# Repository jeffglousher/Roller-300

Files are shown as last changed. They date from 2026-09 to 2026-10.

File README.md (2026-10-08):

# Roller-300

Two-wheel indoor roller under mechanical development. Start the S21 rigid belt drivetrain with the **five-part receiving-fit test**, PETG /0.4mm on the X2D. The larger carrier/fixture and open-face wheel follow successful hardware fits. Whole-chassis fit remains incomplete: the historical hatch collides when restored and electronics mounts are inactive. Strength optimization and powered loads are deferred.

- [Roller-300.nbcad](Roller-300.nbcad): current native CAD model,2,033 features and seven assembly Named Views.
- [Whole-chassis fit review](design/chassis-fit-review-2026-10-07/README.md): native service/access fixes, open-face wheels, exact fit checks and remaining chassis gaps.
- [Adversarial review](design/adversarial-review-2026-10-06/README.md): corrected defects, native images and validation scope.
- [PLAN.md](PLAN.md): current dimensions, retention and assembly order.
- [Small Bambu fit project](first-prints/receiving-fit-gate-2026-10-06/Roller-300-small-fit-gate.3mf): five interfaces, approximately25.48g /1h16m. Open this first.
- [S21 open-face wheel fit project](first-prints/chassis-fit-2026-10-07/outboard-down/Roller-300-wheel-open-fit.3mf): approximately336.71g /8h38m; print after receiving fits pass. Supersedes the closed-wheel files.
- [Fresh print decision](design/print-decision-2026-10-06/README.md): fresh native replay, actual toolpaths and corrected support/settings defects. The original ten-part review plate is superseded.
- [Print set](first-prints/adversarial-fit-2026-10-06/README.md): all eleven pieces and individual slicer checks.
- [BOM.xlsx](BOM.xlsx) and [parts-sources.json](parts-sources.json): current purchase workbook and source record.
- [parameters.json](parameters.json) and [test-record.json](test-record.json): current nominal values, evidence and pending physical tests.

Geometry is authored/replayed and rendered by the installed native CAD application. STEP-based inspection probes and rigid print placement support validation. No print, powered test or purchase has been made. Historical chapter files and previous print folders are retained for reference.

The public repository is https://github.com/jeffglousher/Roller-300. No hardware/source license has been assigned; linked third-party material retains its own terms.

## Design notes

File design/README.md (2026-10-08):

# design/

## Current S20 drivetrain

[Adversarial review](adversarial-review-2026-10-06/README.md) contains the current native captures, exact interference and geometry checks. [Canonical CAD](../Roller-300.nbcad) and [PLAN.md](../PLAN.md) define the current assembly. The chapter files below are historical baselines and do not regenerate S20.

VERSION 0.1 chapters (`VERSION`, `gen_meta.json`). Filenames are `design_v0_1_<role>.nbcad.jsonc`. The `"version": 1` field inside each file is the script schema.

Mechanical decisions are in [`../PLAN.md`](../PLAN.md). Dimensions are in [`../parameters.json`](../parameters.json). The native desktop model is [`../Roller-300.nbcad`](../Roller-300.nbcad).

## Chapters

| File | Stage | Role | Contents |
|---|---|---|---|
| `design_v0_1_hardware_refs.nbcad.jsonc` | S01 | Bearing and nut coupons | Trial 608 seat D22.2×7.2 and M4 nut pocket AF 7.3×3.5 |
| `design_v0_1_barrel_shell.nbcad.jsonc` | S02 | `main_shell` (body 32) | Shell chapter. Standalone file skips MoveCopy5, Combine8, and Combine16. Assemble-order AABB about 159.93×210×159.96. Meshes: `../first-prints/native-port/main-shell.*` |
| `design_v0_1_input_carriage.nbcad.jsonc` | S02 | `left_input_carriage` (body 97) | Left carriage. AABB 39×100×35. Meshes: `../first-prints/native-port/left-input-carriage.*` |
| `design_v0_1_input_caps.nbcad.jsonc` | S02 | Input caps (bodies 100, 108) | Inner and outer. AABB 39×8×17.7. Meshes: `../first-prints/native-port/input-cap-{inner,outer}.*` |
| `design_v0_1_wheel_caps.nbcad.jsonc` | S02 | Wheel caps (bodies 56, 65) | Inner and outer. AABB 50×12×16.7. Meshes: `../first-prints/native-port/wheel-cap-{inner,outer}.*` |
| `design_v0_1_structural_hatch.nbcad.jsonc` | S03 | `hatch` (body 141) | Replay after the shell chapter through Combine3. AABB 138×179.4×79.932. The review STL in `shell-first-review/` is the trimmed export (zmin 154.859). Meshes: `../first-prints/native-port/curved-hatch.*` |
| `design_v0_1_electronics_mounts.nbcad.jsonc` | S04 | Shelf and allowance coupons | Pi, Pixracer, TOF, battery tray, and thermal shelf from recorded nominals. Positive retainers, sensor depth, and the optical aperture stay open until the parts are measured |
| `design_v0_1_drive_stack.nbcad.jsonc` | S01/S05 | Drive envelopes | 24/48 pitch circles, belt torus, and Ø8 stubs. These are envelopes, not tooth geometry |
| `design_v0_1_assemble.nbcad.jsonc` | orchestrator | Chapter order | Empty steps. Order is listed in that file and in `gen_meta.json` → `assemble.chapter_order` |

## Replay

Open a blank document and apply the chapters in `assemble.chapter_order`. These files have no include. A runner has to apply each chapter's steps and remap `$ref` / `let` bindings.

Frame: millimeters; X forward, Y left, Z up; axle Z=123.

Belt cited on the drive chapter: D&D 210-3M-09, pitch 3 mm, pitch length 210 mm, width 9 mm, 70 teeth.

## Meshes

- [`../first-prints/coupons/`](../first-prints/coupons/README.md) — fit coupons
- [`../first-prints/shell-first-review/`](../first-prints/shell-first-review/README.md) — review meshes from the native model
- [`../first-prints/native-port/`](../first-prints/native-port/README.md) — meshes replayed from these chapters

Feature dumps of the native bodies are in [`native-port/`](native-port/README.md).

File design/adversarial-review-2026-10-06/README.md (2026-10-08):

# S20 adversarial drivetrain review

Printing recommendation updated by the [fresh print decision](../print-decision-2026-10-06/README.md): start with the corrected five-part receiving-fit plate. The original ten-part review project is superseded by actual support/bed/settings findings. The geometry and nominal inspection evidence below remain applicable.

S20 corrects assembly defects in the prior nominal model and prepares an unpowered PETG one-drive fit article. [Current model](../../Roller-300.nbcad) and [assembly instructions](../../PLAN.md) are authoritative. No physical validation or powered release is claimed.

## Defects corrected

The earlier shared servo and bridge datums had moved repeatedly. The reference servo ears were12mm from their intended position, bridge bores missed the bridge, and restraints intersected the servo. Native overlap volumes included72.9mm³ with the roof-open fixture,307.8mm³ with its carrier and353.27mm³ with its bridge. Datums/reference ears are now coherent and stationary clearances pass at tested carrier travel.

The bridge lacked valid captures at its actual mounting points. S20 adds rounded posts, side-loaded bridge nuts, four captured ear nuts and lower driver passages. Nut seating, insertion and resistance to rotation are tested against the native solids. Loose nuts require a screw for captivity; a snap fit is not claimed.

The adapter's rotating pinch ear touched its carrier. The24T pulley's5mm clamp hub also could not enclose a conventional M3 nut. Both friction clamps are removed. A stock48mm REX shaft drives AF7.3 printed bores, with factory Eclip and stock rear retention. This simplifies assembly and avoids a fabricated thin collar and1.7mm shim stack.

A positive keyed bore needed a separate axial stop. Integral R5.5 pulley lands now locate it between bearing inner races, leaving0.4mm nominal total play. The shaft uses the Eclip pocket and rear metal stack for0.2mm nominal travel. Native probes verify permitted movement and interference beyond the stops. This establishes nominal geometry, not wear/load capacity.

The output8mm stop now uses stock6+2mm spacers. Right purchased threaded references use rotation, preserving right-hand thread geometry. Printed parts retain their intended mirror geometry.

## Native CAD images

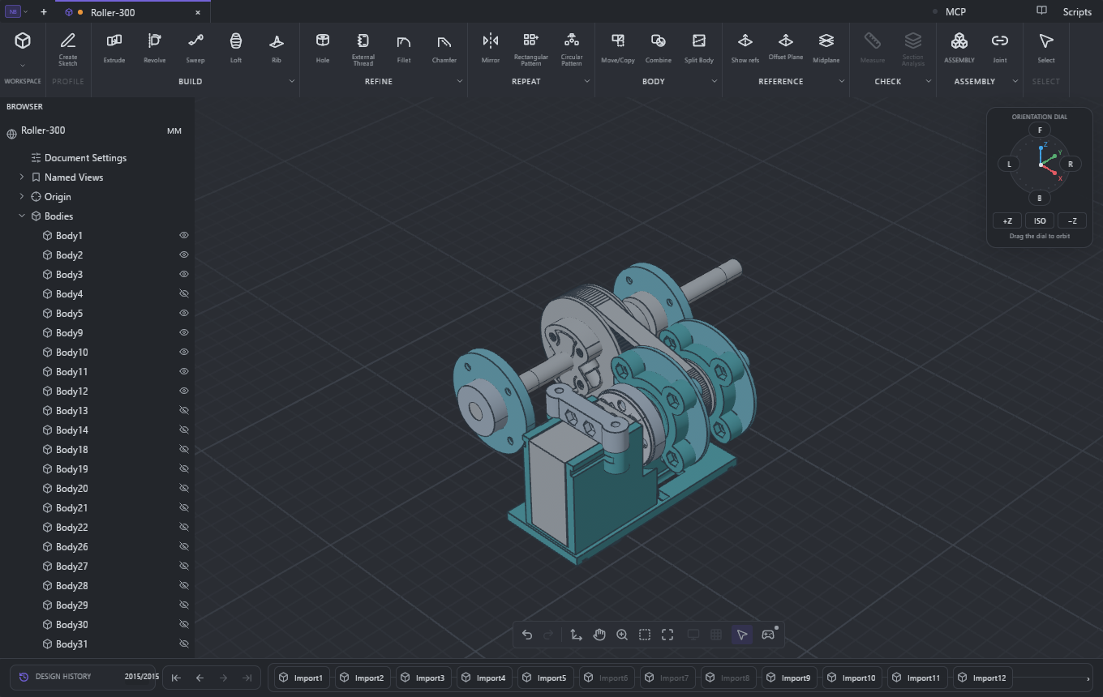
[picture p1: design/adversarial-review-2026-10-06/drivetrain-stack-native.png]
One-drive stack


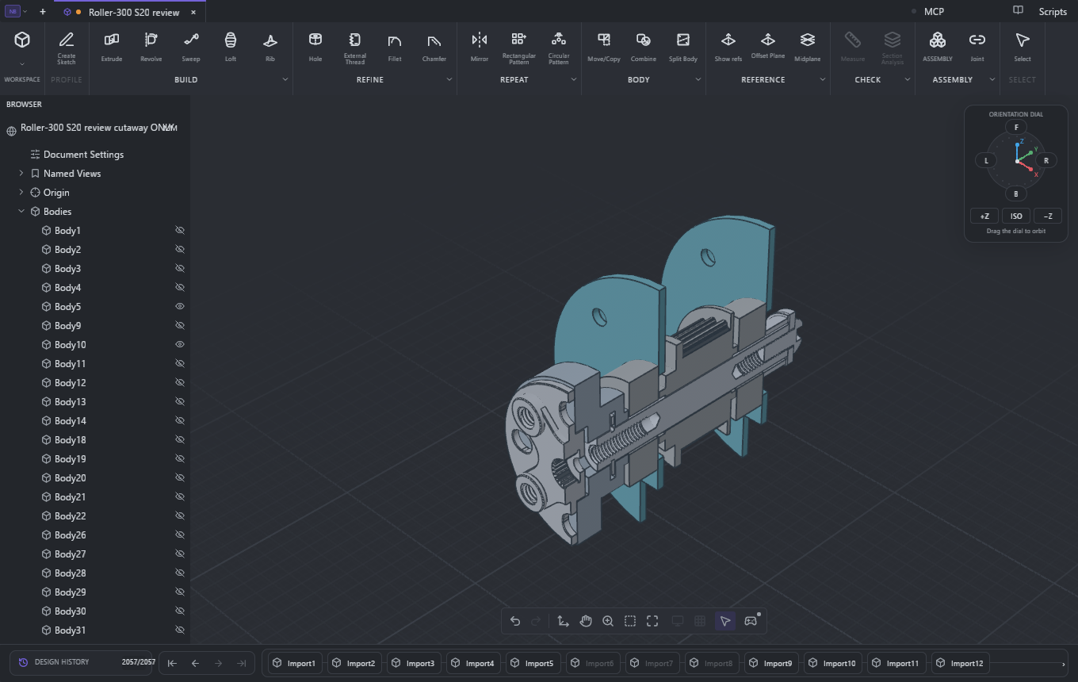
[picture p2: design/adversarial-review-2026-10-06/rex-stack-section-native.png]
REX axial half-section


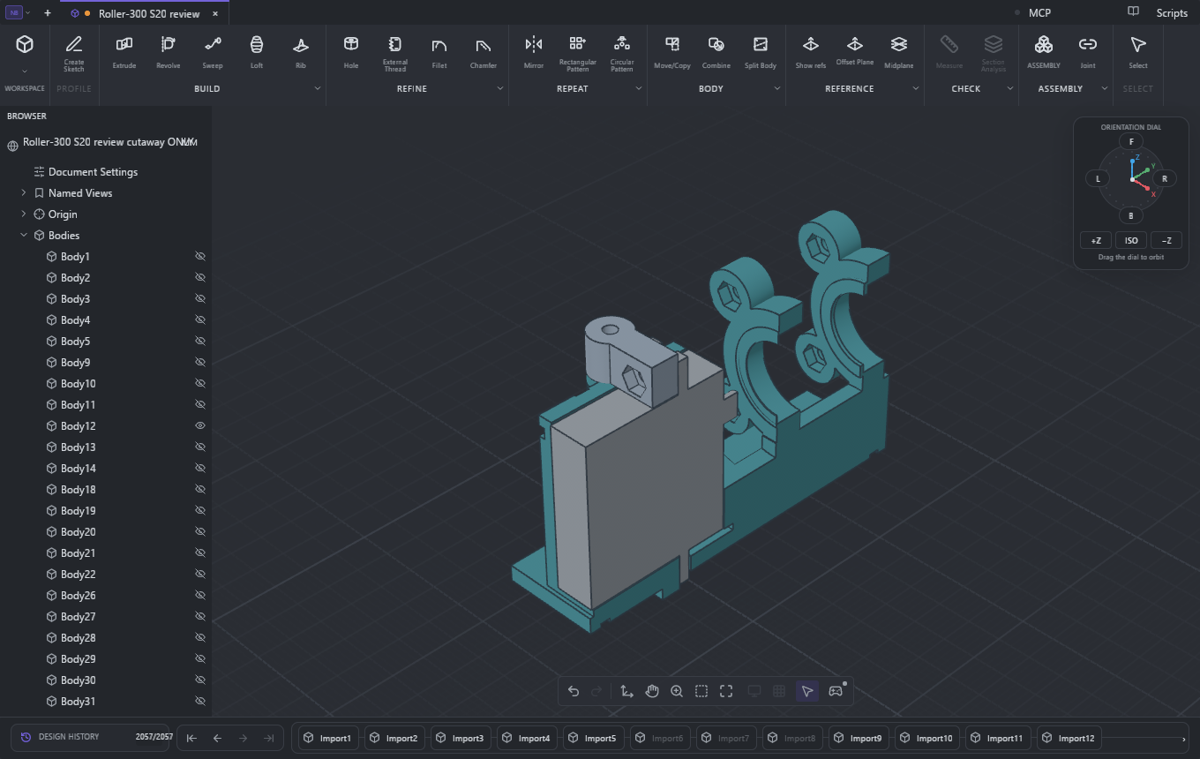
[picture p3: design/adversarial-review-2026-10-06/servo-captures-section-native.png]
Servo captured-nut section


All images are native application captures. [Review cutaway model](Roller-300-review-cutaway.nbcad) removes material only for inspection. **Do not print the cutaway.** The canonical model keeps intact parts. These sections show the left drive; subsequent correction of right stock-reference orientation did not change the pictured left geometry.

## Verification and limits

- [Validation summary](validation-summary.json):496 nominal checks,22 valid connected watertight print bodies,2,015 native features with0 errors, seven recalled Named Views preserving geometry.
- [Drivetrain geometry](checks.json):255 checks, including rotating clearances, travel, horn/hub screw positions and current axial dimensions.
- [Assembly probes](adversarial-checks.json):109 checks of actual stock REX/clip geometry, positive torque engagement, axial stops, nut loading/rotation and driver access on both drives.
- [Existing capture checks](capture-checks.json):122 checks of bearing retainers, carrier captures and trimmed envelope roots.
- [Wall sections](wall-section-checks.json):10 continuous-material gauges. Torque lands and horn rims are approximately1.285mm nominal minimum. One upper servo-nut pocket has a0.95mm local lip backed by4.2mm solid axial material; strength remains a physical qualification.
- [Left native interference](left-roof-open-native-interference.json) and [right native interference](right-full-frame-native-interference.json):27 selected bodies each. The only reported volume overlaps are the coarse belt envelope against its two pulleys and the nominal smooth servo spline against the actual25T horn spline. These references cannot qualify physical tooth/spline fit. Dense threaded REX/screw solids are excluded from this broad sweep and checked separately by the assembly probes. Thread fit and belt meshing remain receiving tests.
- Every native STL matches the current print manifest and slice-check hash. The final Bambu project's ten meshes are compared directly to current print STL triangle coordinates. All11 individual slices and the combined plate pass without warnings. Native preflight assembly-layout warnings are superseded by the separate verified print placements.

Actual PETG bearing/key/nut fit, factory Eclip installation, center-screw length, hardware seating, endplay and belt tracking must be recorded during unpowered assembly. Full-barrel rear screw service access remains obstructed by the upper guard and is deferred with barrel work. Powered shock, torque, heat and reversal loads are untested; the belt provides no calibrated torque limiting.

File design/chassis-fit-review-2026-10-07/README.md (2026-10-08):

# Whole-chassis fit review — 2026-10-07

The small unpowered drivetrain fit test remains the first print. The complete chassis is **not yet a fit release**. This review found and corrected two assembly/print-access defects, and exposed unfinished hatch and electronics interfaces. Strength optimization is deferred.

## Native fit corrections

- Two D4.4 service bores through the full shell's belt guards give a straight 3 mm driver access to the rear carrier screws. Previously each guard obstructed the driver through Z156..164. Bearing seats and the roof-open fixture are unchanged.
- Both wheel faces are opened inside D216. The D230 rim, 40 mm wheel width, 4 mm hub web and its bolt/pilot geometry remain. The former outer plate blocked all four hub-screw drivers; the two closed cavities also trapped approximately 148 g of support paths in the historical wheel slice. The open faces permit screw installation and support cleanup.
- Corrected the current register's old collar/spacer positions and servo case datum. The BOM now separates four M3x10 servo-ear screws from sixteen M3x12 bearing-retainer screws per drive. Exact M3x10 source/price remains open.

S21 adds eighteen native history features to S20, reaching 2,033. Installed Limo CAD replays and exports every changed shape. All ten existing smaller fit-part STL hashes remain identical. Native changes affect full shell32 and wheels13/30; the older closed-wheel print projects are superseded.

## Whole-chassis findings

The historical curved hatch141 and its closure features are suppressed. A separate native restoration candidate had no history errors, but exact inspection found **1,334.910 mm³ of hatch/shell overlap**, plus new input-retainer/carrier interference. Simply enabling the old features does not make a fitting hatch. The failed restoration remains separate from the canonical design.

Battery, Pi/controller, thermal camera, ToF, optical and harness mounting features are also inactive. Their old locating shelves and footprint registers do not constitute a current fitting assembly. Complete received component contours, connector exits, cable bends, positive restraints and service sweeps still need to be incorporated.

The wheels span 300 mm, but the uncut stock shafts end at Y±158: **316 mm actual shaft width**, exceeding the 300 mm target. Bare printed wheel diameter is230 mm; D246 is the tread allowance. Nominal belly clearance is35 mm on bare wheels and43 mm with the8 mm radial tread allowance. The width target and tread interface remain unresolved.

The old closed wheel's 5 mm shell-end gap concealed a smaller0.5 mm clearance to its protruding bearing-retainer bosses. S21 removes that surface: wheel/retainer clearance is24.0 mm nominal,23.8 mm at inward axial travel; minimum wheel/shell clearance is28.3 mm. Physical runout, endplay and hand rotation remain receiving tests.

The metal wheel hub/collar reference envelopes do not include a qualified clamp-screw/tool model. Clamp access and included hardware must be checked on receipt. The wheel bolts use the retained4 mm web, giving6 mm nominal engagement for M4x10 in8 mm deep metal threads; verify actual head/length/pilot seating.

## Printing and assembly gates

1. Print the [five small interfaces](../../first-prints/receiving-fit-gate-2026-10-06/Roller-300-small-fit-gate.3mf): PETG,0.4 mm, approximately25.48 g /1 h16 min. Test the received horn, REX key, center-screw clearance, clip insertion and nut/head fits.
2. Print the [carrier trial](../../first-prints/carrier-roof-trial-2026-10-06/Roller-300-carrier-roof-trial.3mf): approximately55.05 g /2 h22 min. Test both unsupported nut-channel roofs, actual608 seats, alignment, accessible nuts and screw lengths. Its9.116/16.372 mm roof runs are still physically unqualified.
3. Use the existing corrected fixture project and the [S21 open-face wheel project](../../first-prints/chassis-fit-2026-10-07/outboard-down/Roller-300-wheel-open-fit.3mf) after the receiving tests pass. The wheel is outboard-face down, approximately336.71 g /8 h38 min, with a connected annular first layer and at least10.137 mm bed margin. Supports lie below the hub web and are accessible through theD216 opening; pilot and four screw bores contain no support paths. Bench-assemble hub/pulley and input shaft/clip first. Install the E-clip before mounting its carrier; install the wheel through its open face. Check free rotation with axial travel at both ends, then belt seating/tracking.
4. Refit the hatch and active electronics/connector/restraint interfaces before a complete-chassis fit test. Full barrel slicing and support cleanup still require review after those geometry changes.

Do not force shafts through misaligned bearings, clamp bearing outer races with the shaft stops, or use screws that bottom in the metal threads. Record actual hardware, fit, support removal and endplay. No print, order or powered test was submitted.

## Evidence

- `independent/`: fresh S20 native replay, exact access/envelope probes and the failed hatch restoration.
- `fresh-native-wheel-clearances.json`: pre-correction native wheel/shell/cap interference query; explicitly S20 evidence.
- `register-and-bom-audit.json`: active/suppressed feature and record/BOM review.
- `s21-access/`: new native replay/export and exact correction checks.
- `s21-access/native-replay.nbcad` preserves the exact native replay candidate used by the wheel slice, independently of ignored local scratch files. Use `tools/record_chassis_review.py` to verify it against the saved canonical and print projects.
- [Current native CAD overall view](s21-overall-native.png) and [wheel access view](s21-wheel-access-native.png).
- `fresh-native-replay.json`, `print-project-validation.json`, `validation-summary.json`: saved canonical/provenance checks and current fit-project compatibility.
- `wheel-project-validation.json` reconciles the wheel's native replay source to the saved canonical geometry. `bambu-native-gui-verification.json` records reopened settings and a fresh native GUI slice matching336.71 g /8 h38 min.
- [Print and tolerance notes](tolerance-and-print-fit.md): actual fits to measure and historical support/toolpath findings.

The connector, spline/thread, PETG fit and physical support-removal tests are not replaced by nominal CAD or a warning-free slice.

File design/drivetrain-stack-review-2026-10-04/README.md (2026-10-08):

# Individual drivetrain review — 2026-10-04

These images are fresh captures from the native noBS CAD desktop, opened from `Roller-300.nbcad`. No independent renderer was used. The canonical file was not saved or modified for this review.

- `one-drive-stack-native.png`: isolated assembled left drive, without wheel, tread or housing. Orange identifies the current clutch reaction plate and split pressure pads. Magenta identifies the provisional servo shaft clamp; it is not a finalized horn adapter. Grey cylinders at the adjusters are spring envelopes, not detailed spring coils.
- `one-drive-top-native.png`: axial stack and belt alignment viewed from above.
- `one-drive-fixture-native.png`: the same drivetrain installed in its roof-open one-drive fit section.
- `clutch-exploded-native.png`: native assembly occurrence poses separated for illustration. From lower left to upper right: metal shaft hub, reaction plate, front lining, pulley/rotor, rear lining, split pressure pads, one representative adjuster/spring/guide/washer group, removable journal bush. The assembled design uses four adjusters. Explosion distances are illustrative; the pressure pads install radially. All moved occurrence poses were restored after capture.

## Start the fit article independently of the barrel

Use the existing native-export STL files in `first-prints/drivetrain-fit-2026-10-03`. Material/nozzle: PETG, 0.4 mm; the recorded offline slice uses 0.2 mm layers, five walls and 15% gyroid. This is an unpowered fit article. No physical fit has passed yet.

1. Print one each of the mouth, center, input-inboard and input-outboard bearing retainers. Check actual bearings, nut pockets, head seats and driver fit.
2. Print one input sliding carrier and one servo upper bridge. Check servo body/ears, guide fit and bearing seats.
3. Print the roof-open one-drive fit section after those smaller checks pass. Assemble bearings and shaft supports, verify nut loading and driver access, then check free rotation and axial play.
4. Defer the large wheel until the actual metal hub/shaft interface fits. Defer clutch-specific prints if changing the preload mechanism. The current pulley and shaft-clamp trial files remain useful geometry trials, not final powered parts.

## Common hardware that remains useful

For one drive: four 608 bearings (ServoCity 1600-0722-0008, two packs); one 8x150 mm wheel shaft (2100-0008-0150); one 8x50 mm input shaft (2100-0008-0050); one 8 mm wheel Hyper Hub (1310-0016-0008); one 8 mm wheel collar, 9 mm long (2910-0921-0008); one 8x10x3 mm inner-race spacer (1522-0010-0030, one pack); one 210-3M-09 belt (Amazon B00ISC4PHG); one candidate metal 25T round horn (ServoCity 1906-0025-0032). Use the existing BOM for exact common screw packs. Receiving checks still apply; the horn's actual servo spline and center-screw engagement need checking.

Do not substitute the stock 9 mm input collar for the modeled 6 mm collar without revising the stack. The 1.7 mm input shim total and 8x11x8 mm wheel-side spacer remain unresolved purchasing items. Clutch guides, spring washers, friction lining and locking nuts also remain unresolved; do not order guessed equivalents. Buying the common hardware does not complete a working drivetrain.

## Clutch recommendation

The current four independent preload screws are a test layout. Their settings can differ, and the two pressure-pad halves can load unevenly. Equal turns or equal spring lengths do not establish equal measured slip torque between the vehicle's two drives.

Retain a replaceable custom clutch, but develop one common metal preload adjustment acting through a guided, stiff pressure assembly. The threaded adjustment and spring seats should use metal hardware. Keep this force loop independent of the wheel-bearing axial stops. A common adjustment is a recommendation, not geometry implemented in this render; it needs a fresh envelope, insertion and interference pass.

Use one bench fixture to measure each clutch's breakaway and sustained slip torque in both directions, with a known lever radius and tangential force (torque = force x radius). Repeat after bedding the selected liner and after wear/temperature checks. Set both drives to an experimentally justified torque band; no numeric target or tolerance has been qualified. The clutches should normally remain engaged and slip only for overload protection. Wheel-speed feedback, rather than clutch preload, should handle left/right motion matching.

Before powered use: finish the metal-horn adapter and screw retention, resolve input axial stops and wheel opposing spacer, qualify the journal/lining/springs and preload mechanism, and validate the loaded assembly. The full barrel is not required for the present fit test.

Reference for the common adjustment/overload principle: [ComInTec friction torque limiter instructions](https://www.comintec.com/download/instruction-sheets/DF_DE-EN.pdf). This reference does not qualify our printed clutch.

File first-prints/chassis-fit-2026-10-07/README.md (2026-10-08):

# Open-face wheel — selected held candidate

Use [the outboard-face-down project](outboard-down/Roller-300-wheel-open-fit.3mf) after the small receiving and carrier tests: **336.71 g /8 h38 min**. The alternative project in this folder is the first inboard-face-down inspection slice,398.76 g /9 h52 min; keep it as evidence, not a second print job. Both contain the same native wheel geometry. The selected pose shortens the removable support column from23.5 mm to12.5 mm and saves62.05 g /1 h13 min.

Actual selected toolpaths have one connected first-layer ring,10.137 mm minimum main-nozzle bed margin, and supports only atZ0.2..12.4 beneath the web. They are accessible through theD216 opening; no support enters the mounting/pilot bores or upper opening. Actual cleanup and hardware fits still need testing. See [the fresh fit review](../../design/chassis-fit-review-2026-10-07/tolerance-and-print-fit.md).

## Inboard-down inspection alternate

Fresh native wheel body13, open on both faces, placed by rigid rotation/translation only. X2D main nozzle, PETG,0.4 mm,0.2 mm layers,5 walls,15% gyroid, normal auto supports. Estimated 398.76 g /9.87 h. No print submitted.

Use the five-piece receiving gate and carrier trial first. This larger wheel remains HOLD until the received Hyper Hub, M4x10 screws and actual wheel/retainer running clearance are checked. Remove supports through the two D216 face openings, inspect the4 mm mounting web and all four D4.4 screw passages, and verify screw/head/driver access before assembly. The old609 g wheel estimate uses superseded closed-face geometry.

This project is an unpowered fit trial. A warning-free slice and open cleanup path do not qualify dimensional accuracy, support removal quality or load-bearing behavior.

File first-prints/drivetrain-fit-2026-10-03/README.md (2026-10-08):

# Unpowered one-drive fit set

Use PETG and the X2D0.4 mm nozzle. Meshes are native CAD exports with rigid bed placement only. `source.json` identifies source hash, body IDs, quantities and bounds; `slice-checks.json` records offline vendor slices. No print was sent.

Start with reaction plate, **two pressure pads**, shaft-clamp trial, input-pulley clamp trial and retainers to check nuts, heads and clamps. Then print carrier and roof-open section. Section approximately187 g /5.2 hours; carrier55 g /2.2 hours on the recorded0.2 mm /5-wall /15% gyroid PETG profile.

Print **two copies of `clutch-pressure-pad.stl`** per drive. The other12 manifest entries require one each. The closed ring under `superseded` cannot assemble around the integral pulley flanges; do not use it.

Follow `../../PLAN.md` for hardware and assembly order. Load fixed-frame nuts before carrier installation; outer nut uses its side port. Check bearing rotation after tightening, full collar engagement, measured endplay, carrier travel and driver access. The section has its upper guard removed; this evidence does not release the complete barrel.

The servo shaft clamp is a trial. Final horn holes, boss clearance, engagement and axial stack need actual horn measurements. Use a matching metal horn with separate horn-retaining and adapter-mounting screws. Whole-vehicle printing and powered tests remain held, including clutch slip calibration and journal wear.

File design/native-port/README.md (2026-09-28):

# Native feature dumps

Feature dumps of bodies in `Roller-300.nbcad`. The geometry lives in the VERSION 0.1 chapters under `design/`. Each `.json` is the structured dump; the `.md` beside it is the same sequence in readable form. `body-inventory.json` lists bodies in the native model.

| Role | Body | Dump | Chapter |
|---|---|---|---|
| main_shell | 32 | `main_shell-32.md` | `design_v0_1_barrel_shell.nbcad.jsonc` |
| left_input_carriage | 97 | `left_input_carriage-97.md` | `design_v0_1_input_carriage.nbcad.jsonc` |
| input_cap_inner | 100 | `input_cap_inner-100.md` | `design_v0_1_input_caps.nbcad.jsonc` |
| input_cap_outer | 108 | `input_cap_outer-108.md` | `design_v0_1_input_caps.nbcad.jsonc` |
| wheel_cap_inner | 56 | `wheel_cap_inner-56.md` | `design_v0_1_wheel_caps.nbcad.jsonc` |
| wheel_cap_outer | 65 | `wheel_cap_outer-65.md` | `design_v0_1_wheel_caps.nbcad.jsonc` |
| hatch | 141 | `hatch-141.md` | `design_v0_1_structural_hatch.nbcad.jsonc` |

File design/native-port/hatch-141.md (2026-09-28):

# hatch (body 141) — native feature dump

Source: `Roller-300.nbcad` → `model.json` (schema 7). Structured twin: `hatch-141.json`.

## Creation
- **MoveCopy5** (`copy: true`) of **body 32** (main_shell) → **body 141**, identity transform
- Owning combines: **Combine4** intersect tool 142; **Combine13** cut tools 164–171; **Combine14** cut tools 172–179
- Used as tool (keep_tools): Combine8→144, Combine16→32 — **shell chapter** owns those

## Feature sequence (hatch create/modify + required tools)

| fid | Feature | Kind | Notes |
|-----|---|---|---|
| 291 | MoveCopy5 | move_copy | new [141] · from [32] result [141] · T {'x': 0.0, 'y': 0.0, 'z': 0.0} |
| 292 | S03 A rounded curved hatch boundary 180L 120deg datum | datum_plane |  |
| 293 | S03 A rounded curved hatch boundary 180L 120deg | sketch | S03 A rounded curved hatch boundary 180L |
| 294 | Extrude88 | extrude | new_body · extent {'distance': 110.0, 'type': 'distance'} · S03 A rounded curved hatch boundary 180L · new [142] |
| 295 | Combine4 | combine | intersect · tgt [141] · tools [142] |
| 330 | S03 I radial screw clearance master datum | datum_plane |  |
| 331 | S03 I radial screw clearance master | sketch | S03 I radial screw clearance master |
| 332 | Extrude96 | extrude | new_body · extent {'distance': 18.0, 'type': 'distance'} · S03 I radial screw clearance master · new [164] |
| 333 | MoveCopy8 | move_copy | new [164] · from [164] result [164] · T {'x': 0.0, 'y': -75.0, 'z': 0.0} · quat [0.0, 0.4617486132350339, 0.0, 0.8870108331782217] |
| 334 | RectangularPattern5 | rectangular_pattern | new [165, 166, 167] · count 4 spacing 50.0 |
| 335 | Mirror6 | mirror | new [168, 169, 170, 171] |
| 337 | Combine13 | combine | cut · tgt [141] · tools [164, 165, 166, 167, 168, 169, 170, 171] |
| 338 | S03 J 90 degree countersink master datum | datum_plane |  |
| 339 | S03 J 90 degree countersink master | sketch | S03 J 90 degree countersink master |
| 340 | Revolve1 | revolve | new_body · angle 360.0 · S03 J 90 degree countersink master · new [172] |
| 341 | MoveCopy9 | move_copy | new [172] · from [172] result [172] · T {'x': 0.0, 'y': -75.0, 'z': 0.0} · quat [0.0, 0.4617486132350339, 0.0, 0.8870108331782217] |
| 342 | RectangularPattern6 | rectangular_pattern | new [173, 174, 175] · count 4 spacing 50.0 |
| 343 | Mirror7 | mirror | new [176, 177, 178, 179] |
| 344 | Combine14 | combine | cut · tgt [141] · tools [172, 173, 174, 175, 176, 177, 178, 179] |

## AABB check

| Source | AABB (mm) |
|---|---|
| S03 A sketch UV envelope | X ±69 × Y ±89.7 → **138 × 179.4** (2D only; Extrude88 alone ≠ final hatch) |
| `first-prints/shell-first-review/curved-hatch-assembly-coordinates.stl` | X[-69.0000,69.0000] Y[-89.7000,89.7000] Z[154.8591,202.9519] → **138.0000 × 179.4000 × 48.0928** (tris 4296) |
| Blank-doc JSONC replay (shell@fid≤290 → hatch) | X[-69,69] Y[-89.7,89.7] Z[123,202.932] → **138 × 179.4 × 79.932** (tris 3068). XY match. **Z CLOSED**: native matches tall replay; review zmin 154.859 = ID R76 chord at |X|=69 (trimmed export). |X|=69); replay includes Extrude88 plane / Combine3 shoulder material down to Z123. |

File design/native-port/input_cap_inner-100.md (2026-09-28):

# input_cap_inner (body 100) — native feature dump

Source: `Roller-300.nbcad` → `model.json` (schema 7). Structured twin: `input_cap_inner-100.json`.

## Creation
- **Extrude65** (`new_body`) from sketch **S02 R LEFT input cap Y70**
- Datum 65: offset **-66.0** from origin **XZ** (basis origin `[0.0, 66.0, 0.0]`, normal [0.0, -1.0, 0.0])
- Profile: rectangle UV **X 30.0–69.0 × Z 123.3–141.0** (39.0 × 17.700000000000003)
- Extent: **distance 8.0**, `flip: True` → body **100**
- Owning combine: **Combine17** intersect with Extrude144 tool body 234

## Feature sequence (fid order)

| fid | Feature | Op | Sketch / notes | Extent |
|-----|---|----|---|---|
| 217 | Extrude65 | new_body | S02 R LEFT input cap Y70 | 8.0 |
| 220 | Extrude66 | cut | S02 S cap bore Y70 | 8.0 |
| 223 | Extrude67 | cut | S02 T input cap M3 holes Y70 — also targets body **97** | 36.0 |
| 510 | Combine17 | intersect | tool Extrude144 / S02 input cap outside corner limit R70 for tension travel → body 234; keep_tools=True | 210.0 |
| 516 | Extrude145 | cut | S02 recessed M3 cap heads for hatch-ledge clearance — also targets 108/123/124 | 5.0 |
| 275 | Mirror2 | mirror | Sources **[97, 100, 108] → [122, 123, 124]**; **does not mutate 100** | — |

## AABB check

| Source | AABB (mm) |
|---|---|
| Sketch envelope heuristic | X 30.0–69.0, Y 66.0–74.0, Z 123.3–141.0 → **39.0 × 8.0 × 17.700000000000003** |
| `shell-first-review/input-cap-inner-assembly-coordinates.stl` | **39×8×17.7** (30–69, 66–74, 123.3–141) |
| axle-vertical STL | extents **39×17.7×8** (reoriented) |

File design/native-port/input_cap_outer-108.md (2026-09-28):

# input_cap_outer (body 108) — native feature dump

Source: `Roller-300.nbcad` → `model.json` (schema 7). Structured twin: `input_cap_outer-108.json`.

## Creation
- **Extrude72** (`new_body`) from sketch **S02 R LEFT input cap Y96**
- Datum 72: offset **-92.0** from origin **XZ** (basis origin `[0.0, 92.0, 0.0]`, normal [0.0, -1.0, 0.0])
- Profile: rectangle UV **X 30.0–69.0 × Z 123.3–141.0** (39.0 × 17.700000000000003)
- Extent: **distance 8.0**, `flip: True` → body **108**
- Owning combine: **Combine18** intersect with Extrude144 tool body 234

## Feature sequence (fid order)

| fid | Feature | Op | Sketch / notes | Extent |
|-----|---|----|---|---|
| 238 | Extrude72 | new_body | S02 R LEFT input cap Y96 | 8.0 |
| 241 | Extrude73 | cut | S02 S cap bore Y96 | 8.0 |
| 244 | Extrude74 | cut | S02 T input cap M3 holes Y96 — also targets body **97** | 36.0 |
| 511 | Combine18 | intersect | tool Extrude144 / S02 input cap outside corner limit R70 for tension travel → body 234; keep_tools=True | 210.0 |
| 516 | Extrude145 | cut | S02 recessed M3 cap heads for hatch-ledge clearance — also targets 108/123/124 | 5.0 |
| 275 | Mirror2 | mirror | Sources **[97, 100, 108] → [122, 123, 124]**; **does not mutate 108** | — |

## AABB check

| Source | AABB (mm) |
|---|---|
| Sketch envelope heuristic | X 30.0–69.0, Y 92.0–100.0, Z 123.3–141.0 → **39.0 × 8.0 × 17.700000000000003** |
| `shell-first-review/input-cap-outer-assembly-coordinates.stl` | **39×8×17.7** (30–69, 92–100, 123.3–141) |
| axle-vertical STL | extents **39×17.7×8** (reoriented) |

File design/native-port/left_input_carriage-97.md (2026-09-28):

# left_input_carriage (body 97) — native feature dump

Source: `Roller-300.nbcad` → `model.json` (schema 7). Structured twin: `left_input_carriage-97.json`.

## Creation
- **Extrude62** (`new_body`) from sketch **S02 O LEFT adjustable input carriage**
- Datum 62: offset **−2** from origin **XZ** (basis origin `[0, 2, 0]`, normal −Y)
- Profile: rectangle UV **X 30–65 × Z 88–92** (35 × 4)
- Extent: **distance 100**, `flip: true` → body **97**
- No owning `combine`; body is native extrude chain only

## Feature sequence (fid order)

| fid | Feature | Op | Sketch / notes | Extent |
|-----|---|----|---|---|
| 208 | Extrude62 | new_body | S02 O LEFT adjustable input carriage | 100 |
| 211 | Extrude63 | join | S02 P supported input post Y70 (datum Y66) | 8 |
| 214 | Extrude64 | cut | S02 Q bearing seat Y70 — Ø22.2 @ (49.6723, 123) | 8 |
| 223 | Extrude67 | cut | S02 T M3 holes Y70 — also targets body **100** | 36 |
| 226 | Extrude68 | cut | S02 U nut pocket (34.6723, 70) | 7 |
| 229 | Extrude69 | cut | S02 U nut pocket (64.6723, 70) | 7 |
| 232 | Extrude70 | join | S02 P supported input post Y96 (datum Y92) | 8 |
| 235 | Extrude71 | cut | S02 Q bearing seat Y96 | 8 |
| 244 | Extrude74 | cut | S02 T M3 holes Y96 — also targets body **108** | 36 |
| 247 | Extrude75 | cut | S02 U nut pocket (34.6723, 96) | 7 |
| 250 | Extrude76 | cut | S02 U nut pocket (64.6723, 96) | 7 |
| 253 | Extrude77 | cut | S02 V tension slot (34, 56) on Z=87 | 6 |
| 256 | Extrude78 | cut | S02 V tension slot (61, 56) | 6 |
| 259 | Extrude79 | cut | S02 V tension slot (34, 84) | 6 |
| 262 | Extrude80 | cut | S02 V tension slot (61, 84) | 6 |
| 265 | Extrude81 | join | S02 W servo lip X37.6723 | 40.5 |
| 268 | Extrude82 | join | S02 W servo lip X60.1723 | 40.5 |
| 271 | Extrude83 | join | S02 X end stop Y3.5 | 1 |
| 274 | Extrude84 | join | S02 X end stop Y46 | 1 |
| 275 | Mirror2 | mirror | Sources **[97,100,108] → [122,123,124]** about origin XZ; **does not mutate 97** | — |
| 287 | Extrude86 | cut | S02 Z L removable servo strap passages (4 rects) | 6 |

Between these, same S02 block also builds caps (Extrude65/66 → 100, Extrude72/73 → 108) — see JSON `timeline_context_extrudes_not_targeting_97`.

## AABB check (optional)
| Source | AABB (mm) |
|---|---|
| Sketch envelope heuristic | X 30–69, Y 2–102, Z 88–123 → **39 × 100 × 35** |
| `shell-first-review/left-input-carriage-assembly-coordinates.stl` | **exact match** (30–69, 2–102, 88–123) |
| `.../left-input-carriage-floor-down.stl` | −19.5–19.5, −50–50, 0–35 → same extents **39 × 100 × 35** (reoriented) |

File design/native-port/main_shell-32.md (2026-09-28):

# main_shell (body 32) — native feature dump

Source: `Roller-300.nbcad` → `model.json` (schema 7). Structured twin: `main_shell-32.json`.

## Creation
- **Extrude1** (`new_body`) from sketch **S02 A continuous exoskeleton 160OD 152ID 210L**
- Datum 21: offset **105** from origin **XZ** (basis origin `[0, -105, 0]`, normal −Y)
- Profile: concentric circles Ø160 / Ø152 centered UV `(0, 123)` → world axle Z=123
- Extent: **distance 210**, `flip: true` → body **32**
- Owning combines: **Combine1** intersect tools [71], **Combine2** intersect tools [96], **Combine3** join tools [125, 126, 127, 128, 129, 130, 131, 132], **Combine5** cut tools [143], **Combine9** join tools [144], **Combine10** join tools [147, 148, 149, 150, 151, 152, 153, 154], **Combine11** cut tools [155, 157, 158, 159, 160, 161, 162, 163], **Combine12** cut tools [164, 165, 166, 167, 168, 169, 170, 171], **Combine15** intersect tools [217], **Combine16** cut tools [141]
- Used as source: **MoveCopy5** copy → hatch body **141** (identity); hatch chapter owns post-copy hatch ops
- Tool-body prerequisites included (interesting): `[32, 71, 96, 125, 126, 127, 128, 129, 130, 131, 132, 143, 144, 145, 146, 147, 148, 149, 150, 151, 152, 153, 154, 155, 157, 158, 159, 160, 161, 162, 163, 164, 165, 166, 167, 168, 169, 170, 171, 217]`
- Excluded transitive expand: **141** (hatch chain lives in `hatch-141.*`; Combine16 references it)

## Feature sequence (329 features — all fids/ops/extents)

| fid | Feature | Kind | Notes |
|-----|---|---|---|
| 21 | S02 A continuous exoskeleton 160OD 152ID 210L datum | datum_plane |  |
| 22 | S02 A continuous exoskeleton 160OD 152ID 210L | sketch | ents 2 {'circle': 2} · UV 160×160 · origin [0.0, -105.0, 0.0] |
| 23 | Extrude1 | extrude | new_body · extent {'distance': 210.0, 'type': 'distance'} · S02 A continuous exoskeleton 160OD 152ID 210L · new [32] |
| 24 | S02 B integral end guard Y-105 datum | datum_plane |  |
| 25 | S02 B integral end guard Y-105 | sketch | ents 2 {'circle': 2} · UV 160×160 · origin [0.0, -105.0, 0.0] |
| 26 | Extrude2 | extrude | join · extent {'distance': 3.0, 'type': 'distance'} · S02 B integral end guard Y-105 · tgt [32] · new [33] |
| 27 | S02 B integral end guard Y102 datum | datum_plane |  |
| 28 | S02 B integral end guard Y102 | sketch | ents 2 {'circle': 2} · UV 160×160 · origin [0.0, 102.0, 0.0] |
| 29 | Extrude3 | extrude | join · extent {'distance': 3.0, 'type': 'distance'} · S02 B integral end guard Y102 · tgt [32] · new [34] |
| 30 | S02 C output saddle at Y-99 datum | datum_plane |  |
| 31 | S02 C output saddle at Y-99 | sketch | ents 13 {'point': 7, 'line': 6} · UV 50×80 · origin [0.0, -105.0, 0.0] |
| 32 | Extrude4 | extrude | join · extent {'distance': 12.0, 'type': 'distance'} · S02 C output saddle at Y-99 · tgt [32] · new [35] |
| 33 | S02 D 608 lower seat at Y-99 datum | datum_plane |  |
| 34 | S02 D 608 lower seat at Y-99 | sketch | ents 1 {'circle': 1} · UV 22.2×22.2 · origin [0.0, -105.0, 0.0] |
| 35 | Extrude5 | extrude | cut · extent {'distance': 12.0, 'type': 'distance'} · S02 D 608 lower seat at Y-99 · tgt [32] · new [36] |
| 36 | S02 E output cap service clearance Y-99 datum | datum_plane |  |
| 37 | S02 E output cap service clearance Y-99 | sketch | ents 8 {'point': 4, 'line': 4} · UV 50.6×19 · origin [0.0, -105.2, 0.0] |
| 38 | Extrude6 | extrude | cut · extent {'distance': 12.4, 'type': 'distance'} · S02 E output cap service clearance Y-99 · tgt [32] · new [37] |
| 45 | S02 H M4 cap holes Y-99 datum | datum_plane |  |
| 46 | S02 H M4 cap holes Y-99 | sketch | ents 2 {'circle': 2} · UV 40.44×4.472 · origin [0.0, 0.0, 104.0] |
| 47 | Extrude9 | extrude | cut · extent {'distance': 40.0, 'type': 'distance'} · S02 H M4 cap holes Y-99 · tgt [32, 38] · new [40, 41] |
| 48 | S02 I side-load nut pocket (-18, -99) datum | datum_plane |  |
| 49 | S02 I side-load nut pocket (-18, -99) | sketch | ents 8 {'point': 4, 'line': 4} · UV 7.3×3.5 · origin [0.0, -105.1, 0.0] |
| 50 | Extrude10 | extrude | cut · extent {'distance': 10.0, 'type': 'distance'} · S02 I side-load nut pocket (-18, -99) · tgt [32] · new [42] |
| 51 | S02 I side-load nut pocket (18, -99) datum | datum_plane |  |
| 52 | S02 I side-load nut pocket (18, -99) | sketch | ents 8 {'point': 4, 'line': 4} · UV 7.3×3.5 · origin [0.0, -105.1, 0.0] |
| 53 | Extrude11 | extrude | cut · extent {'distance': 10.0, 'type': 'distance'} · S02 I side-load nut pocket (18, -99) · tgt [32] · new [43] |
| 54 | S02 C output saddle at Y-51 datum | datum_plane |  |
| 55 | S02 C output saddle at Y-51 | sketch | ents 13 {'point': 7, 'line': 6} · UV 50×80 · origin [0.0, -57.0, 0.0] |
| 56 | Extrude12 | extrude | join · extent {'distance': 12.0, 'type': 'distance'} · S02 C output saddle at Y-51 · tgt [32] · new [44] |
| 57 | S02 D 608 lower seat at Y-51 datum | datum_plane |  |
| 58 | S02 D 608 lower seat at Y-51 | sketch | ents 1 {'circle': 1} · UV 22.2×22.2 · origin [0.0, -57.0, 0.0] |
| 59 | Extrude13 | extrude | cut · extent {'distance': 12.0, 'type': 'distance'} · S02 D 608 lower seat at Y-51 · tgt [32] · new [45] |
| 60 | S02 E output cap service clearance Y-51 datum | datum_plane |  |
| 61 | S02 E output cap service clearance Y-51 | sketch | ents 8 {'point': 4, 'line': 4} · UV 50.6×19 · origin [0.0, -57.2, 0.0] |
| 62 | Extrude14 | extrude | cut · extent {'distance': 12.4, 'type': 'distance'} · S02 E output cap service clearance Y-51 · tgt [32] · new [46] |
| 69 | S02 H M4 cap holes Y-51 datum | datum_plane |  |
| 70 | S02 H M4 cap holes Y-51 | sketch | ents 2 {'circle': 2} · UV 40.44×4.472 · origin [0.0, 0.0, 104.0] |
| 71 | Extrude17 | extrude | cut · extent {'distance': 40.0, 'type': 'distance'} · S02 H M4 cap holes Y-51 · tgt [32, 47] · new [49, 50] |
| 72 | S02 I side-load nut pocket (-18, -51) datum | datum_plane |  |
| 73 | S02 I side-load nut pocket (-18, -51) | sketch | ents 8 {'point': 4, 'line': 4} · UV 7.3×3.5 · origin [0.0, -57.1, 0.0] |
| 74 | Extrude18 | extrude | cut · extent {'distance': 10.0, 'type': 'distance'} · S02 I side-load nut pocket (-18, -51) · tgt [32] · new [51] |
| 75 | S02 I side-load nut pocket (18, -51) datum | datum_plane |  |
| 76 | S02 I side-load nut pocket (18, -51) | sketch | ents 8 {'point': 4, 'line': 4} · UV 7.3×3.5 · origin [0.0, -57.1, 0.0] |
| 77 | Extrude19 | extrude | cut · extent {'distance': 10.0, 'type': 'distance'} · S02 I side-load nut pocket (18, -51) · tgt [32] · new [52] |
| 78 | S02 C output saddle at Y51 datum | datum_plane |  |
| 79 | S02 C output saddle at Y51 | sketch | ents 13 {'point': 7, 'line': 6} · UV 50×80 · origin [0.0, 45.0, 0.0] |
| 80 | Extrude20 | extrude | join · extent {'distance': 12.0, 'type': 'distance'} · S02 C output saddle at Y51 · tgt [32] · new [53] |
| 81 | S02 D 608 lower seat at Y51 datum | datum_plane |  |
| 82 | S02 D 608 lower seat at Y51 | sketch | ents 1 {'circle': 1} · UV 22.2×22.2 · origin [0.0, 45.0, 0.0] |
| 83 | Extrude21 | extrude | cut · extent {'distance': 12.0, 'type': 'distance'} · S02 D 608 lower seat at Y51 · tgt [32] · new [54] |
| 84 | S02 E output cap service clearance Y51 datum | datum_plane |  |
| 85 | S02 E output cap service clearance Y51 | sketch | ents 8 {'point': 4, 'line': 4} · UV 50.6×19 · origin [0.0, 44.8, 0.0] |
| 86 | Extrude22 | extrude | cut · extent {'distance': 12.4, 'type': 'distance'} · S02 E output cap service clearance Y51 · tgt [32] · new [55] |
| 93 | S02 H M4 cap holes Y51 datum | datum_plane |  |
| 94 | S02 H M4 cap holes Y51 | sketch | ents 2 {'circle': 2} · UV 40.44×4.472 · origin [0.0, 0.0, 104.0] |
| 95 | Extrude25 | extrude | cut · extent {'distance': 40.0, 'type': 'distance'} · S02 H M4 cap holes Y51 · tgt [32, 56] · new [58, 59] |
| 96 | S02 I side-load nut pocket (-18, 51) datum | datum_plane |  |
| 97 | S02 I side-load nut pocket (-18, 51) | sketch | ents 8 {'point': 4, 'line': 4} · UV 7.3×3.5 · origin [0.0, 44.9, 0.0] |
| 98 | Extrude26 | extrude | cut · extent {'distance': 10.0, 'type': 'distance'} · S02 I side-load nut pocket (-18, 51) · tgt [32] · new [60] |
| 99 | S02 I side-load nut pocket (18, 51) datum | datum_plane |  |
| 100 | S02 I side-load nut pocket (18, 51) | sketch | ents 8 {'point': 4, 'line': 4} · UV 7.3×3.5 · origin [0.0, 44.9, 0.0] |
| 101 | Extrude27 | extrude | cut · extent {'distance': 10.0, 'type': 'distance'} · S02 I side-load nut pocket (18, 51) · tgt [32] · new [61] |
| 102 | S02 C output saddle at Y99 datum | datum_plane |  |
| 103 | S02 C output saddle at Y99 | sketch | ents 13 {'point': 7, 'line': 6} · UV 50×80 · origin [0.0, 93.0, 0.0] |
| 104 | Extrude28 | extrude | join · extent {'distance': 12.0, 'type': 'distance'} · S02 C output saddle at Y99 · tgt [32] · new [62] |
| 105 | S02 D 608 lower seat at Y99 datum | datum_plane |  |
| 106 | S02 D 608 lower seat at Y99 | sketch | ents 1 {'circle': 1} · UV 22.2×22.2 · origin [0.0, 93.0, 0.0] |
| 107 | Extrude29 | extrude | cut · extent {'distance': 12.0, 'type': 'distance'} · S02 D 608 lower seat at Y99 · tgt [32] · new [63] |
| 108 | S02 E output cap service clearance Y99 datum | datum_plane |  |
| 109 | S02 E output cap service clearance Y99 | sketch | ents 8 {'point': 4, 'line': 4} · UV 50.6×19 · origin [0.0, 92.8, 0.0] |
| 110 | Extrude30 | extrude | cut · extent {'distance': 12.4, 'type': 'distance'} · S02 E output cap service clearance Y99 · tgt [32] · new [64] |
| 117 | S02 H M4 cap holes Y99 datum | datum_plane |  |
| 118 | S02 H M4 cap holes Y99 | sketch | ents 2 {'circle': 2} · UV 40.44×4.472 · origin [0.0, 0.0, 104.0] |
| 119 | Extrude33 | extrude | cut · extent {'distance': 40.0, 'type': 'distance'} · S02 H M4 cap holes Y99 · tgt [32, 65] · new [67, 68] |
| 120 | S02 I side-load nut pocket (-18, 99) datum | datum_plane |  |
| 121 | S02 I side-load nut pocket (-18, 99) | sketch | ents 8 {'point': 4, 'line': 4} · UV 7.3×3.5 · origin [0.0, 92.9, 0.0] |
| 122 | Extrude34 | extrude | cut · extent {'distance': 10.0, 'type': 'distance'} · S02 I side-load nut pocket (-18, 99) · tgt [32] · new [69] |
| 123 | S02 I side-load nut pocket (18, 99) datum | datum_plane |  |
| 124 | S02 I side-load nut pocket (18, 99) | sketch | ents 8 {'point': 4, 'line': 4} · UV 7.3×3.5 · origin [0.0, 92.9, 0.0] |
| 125 | Extrude35 | extrude | cut · extent {'distance': 10.0, 'type': 'distance'} · S02 I side-load nut pocket (18, 99) · tgt [32] · new [70] |
| 126 | S02 J outer-surface trim tool datum | datum_plane |  |
| 127 | S02 J outer-surface trim tool | sketch | ents 1 {'circle': 1} · UV 160×160 · origin [0.0, -105.0, 0.0] |
| 128 | Extrude36 | extrude | new_body · extent {'distance': 210.0, 'type': 'distance'} · S02 J outer-surface trim tool · new [71] |
| 129 | Combine1 | combine | intersect · tgt [32] · tools [71] · keep_tools=False |
| 130 | S02 K integral rail rib (34, -56) datum | datum_plane |  |
| 131 | S02 K integral rail rib (34, -56) | sketch | ents 9 {'point': 5, 'line': 4} · UV 10×45 · origin [0.0, -62.0, 0.0] |
| 132 | Extrude37 | extrude | join · extent {'distance': 12.0, 'type': 'distance'} · S02 K integral rail rib (34, -56) · tgt [32] · new [72] |
| 133 | S02 L rail M4 hole (34, -56) datum | datum_plane |  |
| 134 | S02 L rail M4 hole (34, -56) | sketch | ents 1 {'circle': 1} · UV 4.4×4.4 · origin [0.0, 0.0, 79.0] |
| 135 | Extrude38 | extrude | cut · extent {'distance': 10.0, 'type': 'distance'} · S02 L rail M4 hole (34, -56) · tgt [32] · new [73] |
| 136 | S02 M rail nut insertion (34, -56) datum | datum_plane |  |
| 137 | S02 M rail nut insertion (34, -56) | sketch | ents 8 {'point': 4, 'line': 4} · UV 7.65×4.5 · origin [0.0, -62.1, 0.0] |
| 138 | Extrude39 | extrude | cut · extent {'distance': 10.0, 'type': 'distance'} · S02 M rail nut insertion (34, -56) · tgt [32] · new [74] |
| 139 | S02 K integral rail rib (61, -56) datum | datum_plane |  |
| 140 | S02 K integral rail rib (61, -56) | sketch | ents 9 {'point': 5, 'line': 4} · UV 10×45 · origin [0.0, -62.0, 0.0] |
| 141 | Extrude40 | extrude | join · extent {'distance': 12.0, 'type': 'distance'} · S02 K integral rail rib (61, -56) · tgt [32] · new [75] |
| 142 | S02 L rail M4 hole (61, -56) datum | datum_plane |  |
| 143 | S02 L rail M4 hole (61, -56) | sketch | ents 1 {'circle': 1} · UV 4.4×4.4 · origin [0.0, 0.0, 79.0] |
| 144 | Extrude41 | extrude | cut · extent {'distance': 10.0, 'type': 'distance'} · S02 L rail M4 hole (61, -56) · tgt [32] · new [76] |
| 145 | S02 M rail nut insertion (61, -56) datum | datum_plane |  |
| 146 | S02 M rail nut insertion (61, -56) | sketch | ents 8 {'point': 4, 'line': 4} · UV 7.65×4 · origin [0.0, -62.1, 0.0] |
| 147 | Extrude42 | extrude | cut · extent {'distance': 10.0, 'type': 'distance'} · S02 M rail nut insertion (61, -56) · tgt [32] · new [77] |
| 148 | S02 K integral rail rib (34, -84) datum | datum_plane |  |
| 149 | S02 K integral rail rib (34, -84) | sketch | ents 9 {'point': 5, 'line': 4} · UV 10×45 · origin [0.0, -90.0, 0.0] |
| 150 | Extrude43 | extrude | join · extent {'distance': 12.0, 'type': 'distance'} · S02 K integral rail rib (34, -84) · tgt [32] · new [78] |
| 151 | S02 L rail M4 hole (34, -84) datum | datum_plane |  |
| 152 | S02 L rail M4 hole (34, -84) | sketch | ents 1 {'circle': 1} · UV 4.4×4.4 · origin [0.0, 0.0, 79.0] |
| 153 | Extrude44 | extrude | cut · extent {'distance': 10.0, 'type': 'distance'} · S02 L rail M4 hole (34, -84) · tgt [32] · new [79] |
| 154 | S02 M rail nut insertion (34, -84) datum | datum_plane |  |
| 155 | S02 M rail nut insertion (34, -84) | sketch | ents 8 {'point': 4, 'line': 4} · UV 7.65×4.5 · origin [0.0, -90.1, 0.0] |
| 156 | Extrude45 | extrude | cut · extent {'distance': 10.0, 'type': 'distance'} · S02 M rail nut insertion (34, -84) · tgt [32] · new [80] |
| 157 | S02 K integral rail rib (61, -84) datum | datum_plane |  |
| 158 | S02 K integral rail rib (61, -84) | sketch | ents 9 {'point': 5, 'line': 4} · UV 10×45 · origin [0.0, -90.0, 0.0] |
| 159 | Extrude46 | extrude | join · extent {'distance': 12.0, 'type': 'distance'} · S02 K integral rail rib (61, -84) · tgt [32] · new [81] |
| 160 | S02 L rail M4 hole (61, -84) datum | datum_plane |  |
| 161 | S02 L rail M4 hole (61, -84) | sketch | ents 1 {'circle': 1} · UV 4.4×4.4 · origin [0.0, 0.0, 79.0] |
| 162 | Extrude47 | extrude | cut · extent {'distance': 10.0, 'type': 'distance'} · S02 L rail M4 hole (61, -84) · tgt [32] · new [82] |
| 163 | S02 M rail nut insertion (61, -84) datum | datum_plane |  |
| 164 | S02 M rail nut insertion (61, -84) | sketch | ents 8 {'point': 4, 'line': 4} · UV 7.65×4 · origin [0.0, -90.1, 0.0] |
| 165 | Extrude48 | extrude | cut · extent {'distance': 10.0, 'type': 'distance'} · S02 M rail nut insertion (61, -84) · tgt [32] · new [83] |
| 166 | S02 K integral rail rib (34, 56) datum | datum_plane |  |
| 167 | S02 K integral rail rib (34, 56) | sketch | ents 9 {'point': 5, 'line': 4} · UV 10×45 · origin [0.0, 50.0, 0.0] |
| 168 | Extrude49 | extrude | join · extent {'distance': 12.0, 'type': 'distance'} · S02 K integral rail rib (34, 56) · tgt [32] · new [84] |
| 169 | S02 L rail M4 hole (34, 56) datum | datum_plane |  |
| 170 | S02 L rail M4 hole (34, 56) | sketch | ents 1 {'circle': 1} · UV 4.4×4.4 · origin [0.0, 0.0, 79.0] |
| 171 | Extrude50 | extrude | cut · extent {'distance': 10.0, 'type': 'distance'} · S02 L rail M4 hole (34, 56) · tgt [32] · new [85] |
| 172 | S02 M rail nut insertion (34, 56) datum | datum_plane |  |
| 173 | S02 M rail nut insertion (34, 56) | sketch | ents 8 {'point': 4, 'line': 4} · UV 7.65×4.5 · origin [0.0, 49.9, 0.0] |
| 174 | Extrude51 | extrude | cut · extent {'distance': 10.0, 'type': 'distance'} · S02 M rail nut insertion (34, 56) · tgt [32] · new [86] |
| 175 | S02 K integral rail rib (61, 56) datum | datum_plane |  |
| 176 | S02 K integral rail rib (61, 56) | sketch | ents 9 {'point': 5, 'line': 4} · UV 10×45 · origin [0.0, 50.0, 0.0] |
| 177 | Extrude52 | extrude | join · extent {'distance': 12.0, 'type': 'distance'} · S02 K integral rail rib (61, 56) · tgt [32] · new [87] |
| 178 | S02 L rail M4 hole (61, 56) datum | datum_plane |  |
| 179 | S02 L rail M4 hole (61, 56) | sketch | ents 1 {'circle': 1} · UV 4.4×4.4 · origin [0.0, 0.0, 79.0] |
| 180 | Extrude53 | extrude | cut · extent {'distance': 10.0, 'type': 'distance'} · S02 L rail M4 hole (61, 56) · tgt [32] · new [88] |
| 181 | S02 M rail nut insertion (61, 56) datum | datum_plane |  |
| 182 | S02 M rail nut insertion (61, 56) | sketch | ents 8 {'point': 4, 'line': 4} · UV 7.65×4 · origin [0.0, 49.9, 0.0] |
| 183 | Extrude54 | extrude | cut · extent {'distance': 10.0, 'type': 'distance'} · S02 M rail nut insertion (61, 56) · tgt [32] · new [89] |
| 184 | S02 K integral rail rib (34, 84) datum | datum_plane |  |
| 185 | S02 K integral rail rib (34, 84) | sketch | ents 9 {'point': 5, 'line': 4} · UV 10×45 · origin [0.0, 78.0, 0.0] |
| 186 | Extrude55 | extrude | join · extent {'distance': 12.0, 'type': 'distance'} · S02 K integral rail rib (34, 84) · tgt [32] · new [90] |
| 187 | S02 L rail M4 hole (34, 84) datum | datum_plane |  |
| 188 | S02 L rail M4 hole (34, 84) | sketch | ents 1 {'circle': 1} · UV 4.4×4.4 · origin [0.0, 0.0, 79.0] |
| 189 | Extrude56 | extrude | cut · extent {'distance': 10.0, 'type': 'distance'} · S02 L rail M4 hole (34, 84) · tgt [32] · new [91] |
| 190 | S02 M rail nut insertion (34, 84) datum | datum_plane |  |
| 191 | S02 M rail nut insertion (34, 84) | sketch | ents 8 {'point': 4, 'line': 4} · UV 7.65×4.5 · origin [0.0, 77.9, 0.0] |
| 192 | Extrude57 | extrude | cut · extent {'distance': 10.0, 'type': 'distance'} · S02 M rail nut insertion (34, 84) · tgt [32] · new [92] |
| 193 | S02 K integral rail rib (61, 84) datum | datum_plane |  |
| 194 | S02 K integral rail rib (61, 84) | sketch | ents 9 {'point': 5, 'line': 4} · UV 10×45 · origin [0.0, 78.0, 0.0] |
| 195 | Extrude58 | extrude | join · extent {'distance': 12.0, 'type': 'distance'} · S02 K integral rail rib (61, 84) · tgt [32] · new [93] |
| 196 | S02 L rail M4 hole (61, 84) datum | datum_plane |  |
| 197 | S02 L rail M4 hole (61, 84) | sketch | ents 1 {'circle': 1} · UV 4.4×4.4 · origin [0.0, 0.0, 79.0] |
| 198 | Extrude59 | extrude | cut · extent {'distance': 10.0, 'type': 'distance'} · S02 L rail M4 hole (61, 84) · tgt [32] · new [94] |
| 199 | S02 M rail nut insertion (61, 84) datum | datum_plane |  |
| 200 | S02 M rail nut insertion (61, 84) | sketch | ents 8 {'point': 4, 'line': 4} · UV 7.65×4 · origin [0.0, 77.9, 0.0] |
| 201 | Extrude60 | extrude | cut · extent {'distance': 10.0, 'type': 'distance'} · S02 M rail nut insertion (61, 84) · tgt [32] · new [95] |
| 202 | S02 N trim rail roots to shell outside datum | datum_plane |  |
| 203 | S02 N trim rail roots to shell outside | sketch | ents 1 {'circle': 1} · UV 160×160 · origin [0.0, -105.0, 0.0] |
| 204 | Extrude61 | extrude | new_body · extent {'distance': 210.0, 'type': 'distance'} · S02 N trim rail roots to shell outside · new [96] |
| 205 | Combine2 | combine | intersect · tgt [32] · tools [96] · keep_tools=False |
| 278 | S02 Y wheel outer-race axial shoulder master datum | datum_plane |  |
| 279 | S02 Y wheel outer-race axial shoulder master | sketch | ents 10 {'arc': 2, 'point': 6, 'line': 2} · UV 22.3×22.3 · origin [0.0, -105.0, 0.0] |
| 280 | Extrude85 | extrude | new_body · extent {'distance': 2.4, 'type': 'distance'} · S02 Y wheel outer-race axial shoulder master · new [125] |
| 281 | RectangularPattern1 | rectangular_pattern | new [126] · from [125] · count 2 spacing 9.6 |
| 282 | RectangularPattern2 | rectangular_pattern | new [127, 128] · from [125, 126] · count 2 spacing 48.0 |
| 283 | Mirror3 | mirror | new [129, 130, 131, 132] · from [125, 126, 127, 128] |
| 284 | Combine3 | combine | join · tgt [32] · tools [125, 126, 127, 128, 129, 130, 131, 132] · keep_tools=False |
| 291 | MoveCopy5 | move_copy | new [141] · from [32] · copy=True · T {'x': 0.0, 'y': 0.0, 'z': 0.0} |
| 296 | S03 B hatch opening with 0p3 perimeter clearance datum | datum_plane |  |
| 297 | S03 B hatch opening with 0p3 perimeter clearance | sketch | ents 21 {'point': 13, 'line': 4, 'arc': 4} · UV 138.6×180 · origin [0.0, 0.0, 123.0] |
| 298 | Extrude89 | extrude | new_body · extent {'distance': 110.0, 'type': 'distance'} · S03 B hatch opening with 0p3 perimeter clearance · new [143] |
| 299 | Combine5 | combine | cut · tgt [32] · tools [143] · keep_tools=False |
| 300 | S03 C curved structural lap ledge R72 to77 datum | datum_plane |  |
| 301 | S03 C curved structural lap ledge R72 to77 | sketch | ents 2 {'circle': 2} · UV 154×154 · origin [0.0, -98.0, 0.0] |
| 302 | Extrude90 | extrude | new_body · extent {'distance': 196.0, 'type': 'distance'} · S03 C curved structural lap ledge R72 to77 · new [144] |
| 303 | S03 D ledge outer boundary datum | datum_plane |  |
| 304 | S03 D ledge outer boundary | sketch | ents 21 {'point': 13, 'line': 4, 'arc': 4} · UV 154.6×196 · origin [0.0, 0.0, 123.0] |
| 305 | Extrude91 | extrude | new_body · extent {'distance': 110.0, 'type': 'distance'} · S03 D ledge outer boundary · new [145] |
| 306 | Combine6 | combine | intersect · tgt [144] · tools [145] · keep_tools=False |
| 307 | S03 E clear center of lap ledge datum | datum_plane |  |
| 308 | S03 E clear center of lap ledge | sketch | ents 21 {'point': 13, 'line': 4, 'arc': 4} · UV 122.6×164 · origin [0.0, 0.0, 123.0] |
| 309 | Extrude92 | extrude | new_body · extent {'distance': 110.0, 'type': 'distance'} · S03 E clear center of lap ledge · new [146] |
| 310 | Combine7 | combine | cut · tgt [144] · tools [146] · keep_tools=False |
| 311 | Combine8 | combine | cut · tgt [144] · tools [141] · keep_tools=True |
| 312 | Combine9 | combine | join · tgt [32] · tools [144] · keep_tools=False |
| 313 | S03 F radial M4 nut boss master datum | datum_plane |  |
| 314 | S03 F radial M4 nut boss master | sketch | ents 1 {'circle': 1} · UV 12×12 · origin [0.0, 0.0, 191.0] |
| 315 | Extrude93 | extrude | new_body · extent {'distance': 8.0, 'type': 'distance'} · S03 F radial M4 nut boss master · new [147] |
| 316 | MoveCopy6 | move_copy | new [147] · from [147] · copy=False · T {'x': 0.0, 'y': -75.0, 'z': 0.0} · quat [0.0, 0.4617486132350339, 0.0, 0.8870108331782217] |
| 317 | RectangularPattern3 | rectangular_pattern | new [148, 149, 150] · from [147] · count 4 spacing 50.0 |
| 318 | Mirror4 | mirror | new [151, 152, 153, 154] · from [147, 148, 149, 150] |
| 319 | Combine10 | combine | join · tgt [32] · tools [147, 148, 149, 150, 151, 152, 153, 154] · keep_tools=False |
| 320 | S03 G hex nut pocket master datum | datum_plane |  |
| 321 | S03 G hex nut pocket master | sketch | ents 13 {'point': 7, 'line': 6} · UV 7.3×8.429 · origin [0.0, 0.0, 193.0] |
| 322 | Extrude94 | extrude | new_body · extent {'distance': 3.5, 'type': 'distance'} · S03 G hex nut pocket master · new [155] |
| 323 | S03 H nut side insertion master datum | datum_plane |  |
| 324 | S03 H nut side insertion master | sketch | ents 8 {'point': 4, 'line': 4} · UV 7.3×7 · origin [0.0, 0.0, 193.0] |
| 325 | Extrude95 | extrude | join · extent {'distance': 3.5, 'type': 'distance'} · S03 H nut side insertion master · tgt [155] · new [156] |
| 326 | MoveCopy7 | move_copy | new [155] · from [155] · copy=False · T {'x': 0.0, 'y': -75.0, 'z': 0.0} · quat [0.0, 0.4617486132350339, 0.0, 0.8870108331782217] |
| 327 | RectangularPattern4 | rectangular_pattern | new [157, 158, 159] · from [155] · count 4 spacing 50.0 |
| 328 | Mirror5 | mirror | new [160, 161, 162, 163] · from [155, 157, 158, 159] |
| 329 | Combine11 | combine | cut · tgt [32] · tools [155, 157, 158, 159, 160, 161, 162, 163] · keep_tools=False |
| 330 | S03 I radial screw clearance master datum | datum_plane |  |
| 331 | S03 I radial screw clearance master | sketch | ents 1 {'circle': 1} · UV 4.4×4.4 · origin [0.0, 0.0, 190.0] |
| 332 | Extrude96 | extrude | new_body · extent {'distance': 18.0, 'type': 'distance'} · S03 I radial screw clearance master · new [164] |
| 333 | MoveCopy8 | move_copy | new [164] · from [164] · copy=False · T {'x': 0.0, 'y': -75.0, 'z': 0.0} · quat [0.0, 0.4617486132350339, 0.0, 0.8870108331782217] |
| 334 | RectangularPattern5 | rectangular_pattern | new [165, 166, 167] · from [164] · count 4 spacing 50.0 |
| 335 | Mirror6 | mirror | new [168, 169, 170, 171] · from [164, 165, 166, 167] |
| 336 | Combine12 | combine | cut · tgt [32] · tools [164, 165, 166, 167, 168, 169, 170, 171] · keep_tools=True |
| 345 | S04 A battery support rib Y-17 datum | datum_plane |  |
| 346 | S04 A battery support rib Y-17 | sketch | ents 8 {'point': 4, 'line': 4} · UV 74×34 · origin [0.0, -18.5, 0.0] |
| 347 | Extrude97 | extrude | join · extent {'distance': 3.0, 'type': 'distance'} · S04 A battery support rib Y-17 · tgt [32] · new [180] |
| 348 | S04 A battery support rib Y17 datum | datum_plane |  |
| 349 | S04 A battery support rib Y17 | sketch | ents 8 {'point': 4, 'line': 4} · UV 74×34 · origin [0.0, 15.5, 0.0] |
| 350 | Extrude98 | extrude | join · extent {'distance': 3.0, 'type': 'distance'} · S04 A battery support rib Y17 · tgt [32] · new [181] |
| 351 | S04 B battery platform for UNMEASURED allowance datum | datum_plane |  |
| 352 | S04 B battery platform for UNMEASURED allowance | sketch | ents 8 {'point': 4, 'line': 4} · UV 82×3 · origin [0.0, -22.0, 0.0] |
| 353 | Extrude99 | extrude | join · extent {'distance': 44.0, 'type': 'distance'} · S04 B battery platform for UNMEASURED allowance · tgt [32] · new [182] |
| 354 | S04 C battery strap passage (-40, -19.5) datum | datum_plane |  |
| 355 | S04 C battery strap passage (-40, -19.5) | sketch | ents 8 {'point': 4, 'line': 4} · UV 12×7 · origin [0.0, -21.0, 0.0] |
| 356 | Extrude100 | extrude | cut · extent {'distance': 3.0, 'type': 'distance'} · S04 C battery strap passage (-40, -19.5) · tgt [32] · new [183] |
| 357 | S04 C battery strap passage (-40, 19.5) datum | datum_plane |  |
| 358 | S04 C battery strap passage (-40, 19.5) | sketch | ents 8 {'point': 4, 'line': 4} · UV 12×7 · origin [0.0, 18.0, 0.0] |
| 359 | Extrude101 | extrude | cut · extent {'distance': 3.0, 'type': 'distance'} · S04 C battery strap passage (-40, 19.5) · tgt [32] · new [184] |
| 360 | S04 C battery strap passage (5, -19.5) datum | datum_plane |  |
| 361 | S04 C battery strap passage (5, -19.5) | sketch | ents 8 {'point': 4, 'line': 4} · UV 12×7 · origin [0.0, -21.0, 0.0] |
| 362 | Extrude102 | extrude | cut · extent {'distance': 3.0, 'type': 'distance'} · S04 C battery strap passage (5, -19.5) · tgt [32] · new [185] |
| 363 | S04 C battery strap passage (5, 19.5) datum | datum_plane |  |
| 364 | S04 C battery strap passage (5, 19.5) | sketch | ents 8 {'point': 4, 'line': 4} · UV 12×7 · origin [0.0, 18.0, 0.0] |
| 365 | Extrude103 | extrude | cut · extent {'distance': 3.0, 'type': 'distance'} · S04 C battery strap passage (5, 19.5) · tgt [32] · new [186] |
| 366 | S04 D battery lateral stop Y-20 datum | datum_plane |  |
| 367 | S04 D battery lateral stop Y-20 | sketch | ents 8 {'point': 4, 'line': 4} · UV 74×3 · origin [0.0, -20.0, 0.0] |
| 368 | Extrude104 | extrude | join · extent {'distance': 1.5, 'type': 'distance'} · S04 D battery lateral stop Y-20 · tgt [32] · new [187] |
| 369 | S04 D battery lateral stop Y18.5 datum | datum_plane |  |
| 370 | S04 D battery lateral stop Y18.5 | sketch | ents 8 {'point': 4, 'line': 4} · UV 74×3 · origin [0.0, 18.5, 0.0] |
| 371 | Extrude105 | extrude | join · extent {'distance': 1.5, 'type': 'distance'} · S04 D battery lateral stop Y18.5 · tgt [32] · new [188] |
| 373 | S04 E Pi support bridge -79 datum | datum_plane |  |
| 374 | S04 E Pi support bridge -79 | sketch | ents 8 {'point': 4, 'line': 4} · UV 46×4 · origin [0.0, -81.0, 0.0] |
| 375 | Extrude106 | extrude | join · extent {'distance': 4.0, 'type': 'distance'} · S04 E Pi support bridge -79 · tgt [32] · new [189] |
| 376 | S04 E Pi support bridge -24 datum | datum_plane |  |
| 377 | S04 E Pi support bridge -24 | sketch | ents 8 {'point': 4, 'line': 4} · UV 46×4 · origin [0.0, -26.0, 0.0] |
| 378 | Extrude107 | extrude | join · extent {'distance': 4.0, 'type': 'distance'} · S04 E Pi support bridge -24 · tgt [32] · new [190] |
| 379 | S04 F Pi integral shelf datum | datum_plane |  |
| 380 | S04 F Pi integral shelf | sketch | ents 8 {'point': 4, 'line': 4} · UV 32×2.5 · origin [0.0, -85.0, 0.0] |
| 381 | Extrude108 | extrude | join · extent {'distance': 67.0, 'type': 'distance'} · S04 F Pi integral shelf · tgt [32] · new [191] |
| 382 | S04 G Pi edge registration -31 datum | datum_plane |  |
| 383 | S04 G Pi edge registration -31 | sketch | ents 8 {'point': 4, 'line': 4} · UV 0.7×1.5 · origin [0.0, -84.0, 0.0] |
| 384 | Extrude109 | extrude | join · extent {'distance': 65.0, 'type': 'distance'} · S04 G Pi edge registration -31 · tgt [32] · new [192] |
| 385 | S04 G Pi edge registration -0.0 datum | datum_plane |  |
| 386 | S04 G Pi edge registration -0.0 | sketch | ents 8 {'point': 4, 'line': 4} · UV 0.7×1.5 · origin [0.0, -84.0, 0.0] |
| 387 | Extrude110 | extrude | join · extent {'distance': 65.0, 'type': 'distance'} · S04 G Pi edge registration -0.0 · tgt [32] · new [193] |
| 388 | S04 H Pixracer support bridge 49 datum | datum_plane |  |
| 389 | S04 H Pixracer support bridge 49 | sketch | ents 8 {'point': 4, 'line': 4} · UV 36×4 · origin [0.0, 47.0, 0.0] |
| 390 | Extrude111 | extrude | join · extent {'distance': 4.0, 'type': 'distance'} · S04 H Pixracer support bridge 49 · tgt [32] · new [194] |
| 391 | S04 H Pixracer support bridge 79 datum | datum_plane |  |
| 392 | S04 H Pixracer support bridge 79 | sketch | ents 8 {'point': 4, 'line': 4} · UV 36×4 · origin [0.0, 77.0, 0.0] |
| 393 | Extrude112 | extrude | join · extent {'distance': 4.0, 'type': 'distance'} · S04 H Pixracer support bridge 79 · tgt [32] · new [195] |
| 394 | S04 I original Pixracer shelf - height and retainers HOLD datum | datum_plane |  |
| 395 | S04 I original Pixracer shelf - height and retainers HOLD | sketch | ents 8 {'point': 4, 'line': 4} · UV 38×3 · origin [0.0, 45.0, 0.0] |
| 396 | Extrude113 | extrude | join · extent {'distance': 38.0, 'type': 'distance'} · S04 I original Pixracer shelf - height and retainers HOLD · tgt [32] · new [196] |
| 397 | S04 I2 inner wheel-cap driver access through board shelves datum | datum_plane |  |
| 398 | S04 I2 inner wheel-cap driver access through board shelves | sketch | ents 2 {'circle': 2} · UV 8×110 · origin [0.0, 0.0, 157.0] |
| 399 | Extrude114 | extrude | cut · extent {'distance': 13.0, 'type': 'distance'} · S04 I2 inner wheel-cap driver access through board shelves · tgt [32] · new [197, 198] |
| 403 | S04 J thermal cradle shell rib -34 datum | datum_plane |  |
| 404 | S04 J thermal cradle shell rib -34 | sketch | ents 8 {'point': 4, 'line': 4} · UV 40×6 · origin [0.0, -35.5, 0.0] |
| 405 | Extrude115 | extrude | join · extent {'distance': 3.0, 'type': 'distance'} · S04 J thermal cradle shell rib -34 · tgt [32] · new [199] |
| 406 | S04 J thermal cradle shell rib 34 datum | datum_plane |  |
| 407 | S04 J thermal cradle shell rib 34 | sketch | ents 8 {'point': 4, 'line': 4} · UV 40×6 · origin [0.0, 32.5, 0.0] |
| 408 | Extrude116 | extrude | join · extent {'distance': 3.0, 'type': 'distance'} · S04 J thermal cradle shell rib 34 · tgt [32] · new [200] |
| 409 | S04 K thermal cradle base datum | datum_plane |  |
| 410 | S04 K thermal cradle base | sketch | ents 8 {'point': 4, 'line': 4} · UV 23×3 · origin [0.0, -37.0, 0.0] |
| 411 | Extrude117 | extrude | join · extent {'distance': 74.0, 'type': 'distance'} · S04 K thermal cradle base · tgt [32] · new [201] |
| 412 | S04 L thermal side registration -37 datum | datum_plane |  |
| 413 | S04 L thermal side registration -37 | sketch | ents 8 {'point': 4, 'line': 4} · UV 14×5 · origin [0.0, -37.0, 0.0] |
| 414 | Extrude118 | extrude | join · extent {'distance': 1.2, 'type': 'distance'} · S04 L thermal side registration -37 · tgt [32] · new [202] |
| 415 | S04 L thermal side registration 35.8 datum | datum_plane |  |
| 416 | S04 L thermal side registration 35.8 | sketch | ents 8 {'point': 4, 'line': 4} · UV 14×5 · origin [0.0, 35.8, 0.0] |
| 417 | Extrude119 | extrude | join · extent {'distance': 1.2, 'type': 'distance'} · S04 L thermal side registration 35.8 · tgt [32] · new [203] |
| 418 | S04 M thermal rear registration datum | datum_plane |  |
| 419 | S04 M thermal rear registration | sketch | ents 8 {'point': 4, 'line': 4} · UV 1.7×4 · origin [0.0, -35.5, 0.0] |
| 420 | Extrude120 | extrude | join · extent {'distance': 71.0, 'type': 'distance'} · S04 M thermal rear registration · tgt [32] · new [204] |
| 421 | S04 M2 thermal strap passage (25.5, -20) datum | datum_plane |  |
| 422 | S04 M2 thermal strap passage (25.5, -20) | sketch | ents 8 {'point': 4, 'line': 4} · UV 2×5 · origin [0.0, -25.0, 0.0] |
| 423 | Extrude121 | extrude | cut · extent {'distance': 10.0, 'type': 'distance'} · S04 M2 thermal strap passage (25.5, -20) · tgt [32] · new [205] |
| 424 | S04 M2 thermal strap passage (25.5, 20) datum | datum_plane |  |
| 425 | S04 M2 thermal strap passage (25.5, 20) | sketch | ents 8 {'point': 4, 'line': 4} · UV 2×5 · origin [0.0, 15.0, 0.0] |
| 426 | Extrude122 | extrude | cut · extent {'distance': 10.0, 'type': 'distance'} · S04 M2 thermal strap passage (25.5, 20) · tgt [32] · new [206] |
| 427 | S04 M2 thermal strap passage (42.5, -20) datum | datum_plane |  |
| 428 | S04 M2 thermal strap passage (42.5, -20) | sketch | ents 8 {'point': 4, 'line': 4} · UV 2×5 · origin [0.0, -25.0, 0.0] |
| 429 | Extrude123 | extrude | cut · extent {'distance': 10.0, 'type': 'distance'} · S04 M2 thermal strap passage (42.5, -20) · tgt [32] · new [207] |
| 430 | S04 M2 thermal strap passage (42.5, 20) datum | datum_plane |  |
| 431 | S04 M2 thermal strap passage (42.5, 20) | sketch | ents 8 {'point': 4, 'line': 4} · UV 2×5 · origin [0.0, 15.0, 0.0] |
| 432 | Extrude124 | extrude | cut · extent {'distance': 10.0, 'type': 'distance'} · S04 M2 thermal strap passage (42.5, 20) · tgt [32] · new [208] |
| 433 | S04 N sensor locating rail Z109 datum | datum_plane |  |
| 434 | S04 N sensor locating rail Z109 | sketch | ents 8 {'point': 4, 'line': 4} · UV 7×3 · origin [0.0, -48.0, 0.0] |
| 435 | Extrude125 | extrude | join · extent {'distance': 96.0, 'type': 'distance'} · S04 N sensor locating rail Z109 · tgt [32] · new [209] |
| 436 | S04 N sensor locating rail Z127 datum | datum_plane |  |
| 437 | S04 N sensor locating rail Z127 | sketch | ents 8 {'point': 4, 'line': 4} · UV 7×3 · origin [0.0, -48.0, 0.0] |
| 438 | Extrude126 | extrude | join · extent {'distance': 96.0, 'type': 'distance'} · S04 N sensor locating rail Z127 · tgt [32] · new [210] |
| 447 | S04 O harness saddle -65 datum | datum_plane |  |
| 448 | S04 O harness saddle -65 | sketch | ents 8 {'point': 4, 'line': 4} · UV 12×5 · origin [0.0, -71.0, 0.0] |
| 449 | Extrude127 | extrude | join · extent {'distance': 12.0, 'type': 'distance'} · S04 O harness saddle -65 · tgt [32] · new [211] |
| 450 | S04 P harness tie passage -65 datum | datum_plane |  |
| 451 | S04 P harness tie passage -65 | sketch | ents 8 {'point': 4, 'line': 4} · UV 10×2 · origin [0.0, -67.0, 0.0] |
| 452 | Extrude128 | extrude | cut · extent {'distance': 4.0, 'type': 'distance'} · S04 P harness tie passage -65 · tgt [32] · new [212] |
| 453 | S04 O harness saddle 0 datum | datum_plane |  |
| 454 | S04 O harness saddle 0 | sketch | ents 8 {'point': 4, 'line': 4} · UV 12×5 · origin [0.0, -6.0, 0.0] |
| 455 | Extrude129 | extrude | join · extent {'distance': 12.0, 'type': 'distance'} · S04 O harness saddle 0 · tgt [32] · new [213] |
| 456 | S04 P harness tie passage 0 datum | datum_plane |  |
| 457 | S04 P harness tie passage 0 | sketch | ents 8 {'point': 4, 'line': 4} · UV 10×2 · origin [0.0, -2.0, 0.0] |
| 458 | Extrude130 | extrude | cut · extent {'distance': 4.0, 'type': 'distance'} · S04 P harness tie passage 0 · tgt [32] · new [214] |
| 459 | S04 O harness saddle 65 datum | datum_plane |  |
| 460 | S04 O harness saddle 65 | sketch | ents 8 {'point': 4, 'line': 4} · UV 12×5 · origin [0.0, 59.0, 0.0] |
| 461 | Extrude131 | extrude | join · extent {'distance': 12.0, 'type': 'distance'} · S04 O harness saddle 65 · tgt [32] · new [215] |
| 462 | S04 P harness tie passage 65 datum | datum_plane |  |
| 463 | S04 P harness tie passage 65 | sketch | ents 8 {'point': 4, 'line': 4} · UV 10×2 · origin [0.0, 63.0, 0.0] |
| 464 | Extrude132 | extrude | cut · extent {'distance': 4.0, 'type': 'distance'} · S04 P harness tie passage 65 · tgt [32] · new [216] |
| 465 | S04 Q trim direct mounts at outside barrel surface datum | datum_plane |  |
| 466 | S04 Q trim direct mounts at outside barrel surface | sketch | ents 1 {'circle': 1} · UV 160×160 · origin [0.0, -105.0, 0.0] |
| 467 | Extrude133 | extrude | new_body · extent {'distance': 210.0, 'type': 'distance'} · S04 Q trim direct mounts at outside barrel surface · new [217] |
| 468 | Combine15 | combine | intersect · tgt [32] · tools [217] · keep_tools=False |
| 476 | S02 assembly L outer bearing lowering clearance datum | datum_plane |  |
| 477 | S02 assembly L outer bearing lowering clearance | sketch | ents 8 {'point': 4, 'line': 4} · UV 24×24 · origin [0.0, 102.0, 0.0] |
| 478 | Extrude136 | extrude | cut · extent {'distance': 1.0, 'type': 'distance'} · S02 assembly L outer bearing lowering clearance · tgt [32] · new [220] |
| 486 | S02 assembly R outer bearing lowering clearance datum | datum_plane |  |
| 487 | S02 assembly R outer bearing lowering clearance | sketch | ents 8 {'point': 4, 'line': 4} · UV 24×24 · origin [0.0, -103.0, 0.0] |
| 488 | Extrude139 | extrude | cut · extent {'distance': 1.0, 'type': 'distance'} · S02 assembly R outer bearing lowering clearance · tgt [32] · new [223] |
| 505 | Combine16 | combine | cut · tgt [32] · tools [141] · keep_tools=True |

## Feature counts

- **combine**: 13
- **datum_plane**: 101
- **extrude**: 101
- **mirror**: 4
- **move_copy**: 4
- **rectangular_pattern**: 5
- **sketch**: 101
- **total**: 329

## AABB check

| Source | AABB (mm) |
|---|---|
| Seed sketch S02 A UV (circles Ø160/Ø152) | U[-80.0,80.0] V[43.0,203.0] → **160.0 × 160.0** |
| `first-prints/shell-first-review/main-shell-assembly-coordinates.stl` | X[-79.9502,80.0000] Y[-105.0000,105.0000] Z[43.0125,202.9875] → **159.9502 × 210.0000 × 159.9751** (tris 18188) |
| `first-prints/shell-first-review/main-shell-axle-vertical.stl` | X[-79.9751,79.9751] Y[-79.9875,79.9875] Z[0.0000,210.0000] → **159.9502 × 159.9751 × 210.0000** (tris 18188) |
| Assemble-order replay (w/ Combine16) | X[-79.9259,80] Y[-105,105] Z[43.0185,202.9815] → **159.9259 × 210 × 159.9630** (tris ~13458); MoveCopy5+Combine8+Combine16 applied |

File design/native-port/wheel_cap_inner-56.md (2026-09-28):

# wheel_cap_inner (body 56) — native feature dump

Source: `Roller-300.nbcad` → `model.json` (schema 7). Structured twin: `wheel_cap_inner-56.json`.

## Creation
- **Extrude23** (`new_body`) from sketch **S02 F removable wheel cap Y51**
- Datum 23: offset **-45.0** from origin **XZ** (basis origin `[0.0, 45.0, 0.0]`, normal [0.0, -1.0, 0.0])
- Profile: rectangle UV **X -25.0–25.0 × Z 123.3–140.0** (50.0 × 16.700000000000003)
- Extent: **distance 12.0**, `flip: True` → body **56**
- Owning combine: **none** (no later intersect/recess on this body)

## Feature sequence (fid order)

| fid | Feature | Op | Sketch / notes | Extent |
|-----|---|----|---|---|
| 89 | Extrude23 | new_body | S02 F removable wheel cap Y51 | 12.0 |
| 92 | Extrude24 | cut | S02 G cap seat Y51 — targets [56] | 12.0 |
| 95 | Extrude25 | cut | S02 H M4 cap holes Y51 — targets [32, 56] | 40.0 |

## AABB check

| Source | AABB (mm) |
|---|---|
| Sketch envelope heuristic | X -25.0–25.0, Y 45.0–57.0, Z 123.3–140.0 → **50.0 × 12.0 × 16.700000000000003** |
| `first-prints/shell-first-review/wheel-cap-inner-assembly-coordinates.stl` | **50×12×16.7** (-25–25, 45–57, 123.3–140) |
| axle-vertical STL | extents **50×16.7×12** (reoriented) |

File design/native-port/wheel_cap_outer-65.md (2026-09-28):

# wheel_cap_outer (body 65) — native feature dump

Source: `Roller-300.nbcad` → `model.json` (schema 7). Structured twin: `wheel_cap_outer-65.json`.

## Creation
- **Extrude31** (`new_body`) from sketch **S02 F removable wheel cap Y99**
- Datum 31: offset **-93.0** from origin **XZ** (basis origin `[0.0, 93.0, 0.0]`, normal [0.0, -1.0, 0.0])
- Profile: rectangle UV **X -25.0–25.0 × Z 123.3–140.0** (50.0 × 16.700000000000003)
- Extent: **distance 12.0**, `flip: True` → body **65**
- Owning combine: **none** (no later intersect/recess on this body)

## Feature sequence (fid order)

| fid | Feature | Op | Sketch / notes | Extent |
|-----|---|----|---|---|
| 113 | Extrude31 | new_body | S02 F removable wheel cap Y99 | 12.0 |
| 116 | Extrude32 | cut | S02 G cap seat Y99 — targets [65] | 12.0 |
| 119 | Extrude33 | cut | S02 H M4 cap holes Y99 — targets [32, 65] | 40.0 |

## AABB check

| Source | AABB (mm) |
|---|---|
| Sketch envelope heuristic | X -25.0–25.0, Y 93.0–105.0, Z 123.3–140.0 → **50.0 × 12.0 × 16.700000000000003** |
| `first-prints/shell-first-review/wheel-cap-outer-assembly-coordinates.stl` | **50×12×16.7** (-25–25, 93–105, 123.3–140) |
| axle-vertical STL | extents **50×16.7×12** (reoriented) |

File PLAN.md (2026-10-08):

# Roller-300 — chassis access and positive REX belt drivetrain, 2026-10-07

Canonical model: `Roller-300.nbcad`, S21, 2,033 native history features. Saved through installed Limo CAD0.2.2 File/Save. Saved geometry exactly matches the validated native replay. S21 exports, exact access/fit checks and native captures are in `design/chassis-fit-review-2026-10-07`; ten smaller drivetrain print meshes remain identical to S20. S20 is preserved in `.local/before-s21-chassis-fit.nbcad.bak`. Earlier drivetrain evidence remains in `design/adversarial-review-2026-10-06`.

Scope: **unpowered, roof-open, one-drive fit and assembly test**, PETG,0.4mm nozzle on the X2D. Print the five small receiving-fit pieces first. Larger carrier/fixture and wheel prints follow successful hardware/PETG fits. No physical print, purchase or powered test has occurred. Full barrel and powered operation remain deferred.

## Adversarial corrections

- Restored shared servo/bridge datums once. Repeated datum moves had put servo ears and bridge restraints inside the servo and placed vertical bridge bores outside the bridge.
- Rounded bridge posts and fitted two side-loaded M3 captures. Four servo ear screws now also use captured nuts. Lower pad support and through-driver passages remove the former base obstruction.
- Removed both input pinch joints. The24T pulley's5mm hub could not enclose its M3 nut reliably, and the adapter's rotating pinch ear touched the carrier.
- Replaced the smooth input shaft/custom thin collar/1.7mm shim with stock48mm REX shaft, factory Eclip and catalog rear retention. Positive AF7.3 bores put the torque connection in the printed parts.
- Added integral pulley inner-race lands. A keyed bore alone did not stop axial pulley movement. Lands give0.4mm total nominal play and stop further movement at the bearing inner races.
- Replaced the unsourced8mm output stop with stock6+2mm metal spacers. Purchased horn, REX shaft and threaded end screw on the right use rotation to preserve handedness.

## Input shaft, horn and axial retention

Purchased horn: goBILDA1906-0025-0032 H25T metal servo hub, native manufacturer STEP. INJORA specifies25T/5.9mm for the owned continuous360 servo. The supplied drawing dimensions the case/ears and labels a270 variant. Its explicit37.5mm case height is used provisionally; the40.5mm table conflicts with the diagram. Received360 geometry still needs a fit check.

Left nominal positions in mm:

- Servo baseY0.5, case front38.0, spline tip42.0, ear thickness25.2..27.9.
- Horn spline entry39.0, mounting face41.6, pilot/center-screw head seat43.6. Four M4x6 heads seat at45.1, with2.5mm nominal metal engagement. Pattern16mm square, adapter D14.4/depth2.8 pilot clearance.
- A nominal low-profile M3 center head D5.7 x1.65 ends at45.25. Nominal REX starts46.5:1.25mm gap,0.883mm conservative gap to the imported shaft STEP's thread overshoot. Select actual center-screw length to seat without bottoming. Install it before inserting the input shaft.
- Stock2106-4008-0480 REX shaft spans46.5..94.5, with M4 tapped ends and factory Eclip49.8..50.5. Adapter pocket49.5..50.7 has a radial insertion window. Adapter and pulley have AF7.3 bores for nominal D8/AF7 stock.
- Input608 bearings54..61 and81..88; adapter race land ends53.8. Pulley R5.5 lands extend61.2..80.8, leaving0.4mm total nominal pulley play. Main rear flange ends79.5,0.5mm from stationary housing nominally and0.3mm at allowed travel.
- Rear stock6mm spacer88..94,0.5mm shim94..94.5,1.5mm washer94.5..96, and M4x8 button screw into the shaft end. Nominal screw engagement6.5mm. Rear metal stack and Eclip pocket give0.2mm nominal shaft travel. Check measured endplay/free rotation; do not preload bearing outer races.

The Eclip is a spring part: remove it before sliding the shaft through bearings/pulley, then install it through the adapter's window with its opening facing the shaft. Fit/remove it with the input module on the bench, before mounting the carrier in the fixture. A tested0.8x3mm flat pusher clears the bench module but intersects the installed fixture. Native probes verify printed access, not clip spring force or fatigue.

## Servo captures and carrier

Each servo uses four M3x10 ear screws. Lower AF6/depth2.8 nut pockets load from the front before installing the servo; upper bridge nuts load from the back. Two vertical M3x16 pan-head bridge screws seat atZ143.25 and terminate127.25. Bridge nuts side-load through extended ports intoZ128.7..131.5 pockets. Nominal M3 nuts are AF5.5/height2.4. Hex flats resist rotation, and installed screws prevent sideways escape. Loose nuts are not snap-retained.

Rounded OD10 posts atX34.1723 and65.1723,Y21.7 support the removable bridge. Lower nut pads have solid backing; lower bolt/head/driver corridors clear the carrier base. A0.95mm local upper nut-pocket lip is backed by4.2mm solid axial material. This revision qualifies nominal fit, not powered plastic joint strength.

Servo, horn, bearings, shaft, pulley and rear retention move together on carriers437/440. Guide keys constrain transverse movement. TravelX-2..+1mm about nominal24/48T center distance49.6723mm permits belt installation/adjustment; it does not prescribe belt stretch or tension.

Three M4x14 carrier screws per drive use9x4.3x0.8mm washers and AF7/height3.2 M4 nuts. Left fixed centers:(32.5,12),(60,50),(30.5,79). Outer nut loads horizontally through its side port; the other nuts load from below with carrier removed. Captures and driver access pass for the roof-open section373. S21 adds D4.4 vertical service bores atX30.5,Y±79 through the full-frame guardZ156..164; D3 drivers clear with0.7mm radial allowance. Use the bores with the chassis open.

## Output support and rigid belt

Uncut smooth8x150mm wheel shaft spansY8..158. Two stationary608 bearings at8..15 and98..105 provide90mm center span. Outer races seat against printed shoulders and removable retainers. The redundant rotating wheel bearing is retired.

The uncut shafts produce316mm hardware width versus the300mm wheel-face target. S21 opens both wheel faces insideD216, retaining theD230/40mm rim and4mm hub web. The fourM4x10 wheel bolts can be inserted/driven through the open face. Native wheel/retainer clearance is24mm nominal and23.8mm at inward axial travel; minimum wheel/full-shell gap is28.3mm. Bare-wheel belly clearance is35mm;43mm assumes theD246 tread allowance. The width target and tread attachment remain open.

Wheel axial stops: metal collar85.8..94.8 and3mm inner-race spacer94.8..97.8, opposed by stock1522-0010-0060 spacer105..111 plus1522-0010-0020 spacer111..113 against the wheel hub. Total8mm, nominal D10/ID8. Wheel endplay0.2mm is a receiving setting. Verify the hub's actual rear abutment and free rotation before tightening.

The48T printed output pulley remainsY65.25..79.75,14.5mm long,8.4mm shaft clearance. Purchased1309-0016-0008 Sonic hub mounting face65.25, D14 pilot to67.25; pulley pilot recessD14.2/depth2.2. Four M4x16 button screws use16mm square pattern, D4.5 bores, D8/depth4.7 recesses. Head seat75.05 leaves9.8mm plastic to the hub face and6.2mm nominal metal thread engagement. Bolt hub/pulley together on the bench; rear bearing obstructs installed straight screwdriver access. Tighten shaft clamp with input carrier removed.

Torque path: servo, metal horn, printed positive REX adapter, supported keyed input shaft,24T pulley,210-3M-09 belt, rigid48T pulley, metal Sonic hub, wheel shaft, metal wheel hub and printed wheel. Ratio2:1; belt bandY68..77. Mechanical clutch and all friction/spring/adjuster hardware are retired. No mechanical torque limiter is fitted; a toothed belt is not a calibrated overload release. Powered loads, reversal/shock and temperatures remain unqualified.

## Unpowered assembly order

1. Check small keyed bores, nut captures, head seats and bearing seats with received hardware. Remove supports carefully. Confirm servo center-screw seating before the larger fixture/wheel prints.
2. Load fixed-frame M4 nuts, fit stationary wheel bearings/retainers and leave input carrier out.
3. Bench-bolt48T pulley to Sonic hub with four M4x16 screws; verify pilot/engagement. Place loose belt around the pulley.
4. Lower hub/pulley into roof-open section. Thread wheel shaft through both bearings and hub, placing collar and stock spacers as above. Tighten hub clamp with carrier removed; check hand rotation and measured wheel endplay. Install the open-face wheel and metal wheel hub with fourM4x10 bolts through the exposed hub web; verify actual clamp-tool access before closing anything.
5. Bench-bolt metal horn to positive REX adapter with four M4x6 screws. Fit it to servo and install low-profile center screw through adapter bore. Verify seating and shaft clearance.
6. Load four servo ear nuts and two bridge nuts. Fit servo/bridge to carrier with four M3x10 and two M3x16 screws. Fit input bearings/retainers and loose keyed pulley between them.
7. Remove factory Eclip, slide REX shaft through rear bearing, pulley, front bearing and adapter. Reinstall clip through radial window. Fit rear6mm spacer,0.5mm shim, washer and M4x8 end screw. Check hand rotation, shaft/pulley endplay and inner-race contacts.
8. Offer carrier into frame at reduced center distance, fit belt, then move/clamp carrier with three M4x14 screws/washers. Confirm free hand rotation, tooth seating and flange tracking. Record actual fits; no powered test in this article.

## Evidence, printing and purchasing

`design/adversarial-review-2026-10-06/validation-summary.json`:496 nominal geometry/assembly checks,22 valid connected watertight print bodies, seven persistent native Named Views and0 history errors. Native exact interference checked27 selected bodies per side. Only simplified belt/tooth and nominal servo-spline reference overlaps remain. Dense threaded REX/screw solids were inspected separately with exported native geometry probes; no manufactured spline/thread/belt mesh qualification is claimed.

Native export preflight contains layout warnings because bodies are in assembly positions. It is not the print arrangement. S21 freshly rechecked three existing fit projects against ten unchanged native meshes within0.00005mm after translation. The open-face wheel has a separate fresh native export and rigidly placed slice; the old closed-wheel print is superseded.

Current first print: `first-prints/receiving-fit-gate-2026-10-06/Roller-300-small-fit-gate.3mf`, five unchanged native parts, approximately25.48g /1h16m. X2D, PETG,0.4mm,0.2mm layers,5 walls,15% gyroid. The clip cavity is free of support paths and its roof bridges; actual clip seating after printing is a test target. Bambu GUI reopening and fresh reslicing preserve these settings and agree with the CLI estimate. These five interfaces do not qualify the later carrier's608 housing seats or complete shaft endplay.

The old ten-part review project is superseded: its G-code filled narrow clip/nut channels with support, placed an output-pulley brim fractionally beyond the bed, and its GUI reopened with default process settings. The separately corrected full plate has support-free clip/nut channels and improved bed margins. Check the small hardware fits first, then trial the carrier's unsupported channel roofs and nut insertion before spending material on the larger fixture. The S21 open-face wheel is approximately336.71g /8h38m, outboard-face down with accessible supports; it follows receiving fits. The old609.4g closed-wheel project is superseded. Current evidence is in `design/chassis-fit-review-2026-10-07`, with prior toolpath fixes in `design/print-decision-2026-10-06`. No print sent.

Full-chassis fit remains incomplete. The suppressed historical hatch collides when restored; electronics/optics/harness mounts are inactive and require received geometry and positive retention. The uncut316mm shaft envelope does not meet the300mm wheel-width target. These are fit/interface issues to resolve before full-shell printing, separate from deferred strength work.

Seven native Named Views: overall, roof-open fit, drivetrain stack, output hub, horn/adapter, servo captures and positive REX input. `design/assembly-view-presets.json` mirrors them; view recalls preserve solid geometry. The additional `Roller-300-review-cutaway.nbcad` is inspection only: its removed half-sections must never be printed.

`BOM.xlsx` and `parts-sources.json` contain current stock retention and fasteners. Partial priced purchase subtotals:$100.12 first drive /$173.59 two drives, crediting confirmed ownership. Excludes tax, shipping, filament, unresolved hardware and final electronics. Exact carrier washer source, wheel fasteners and center-screw length remain receiving/sourcing checks. Other catalog offers retain their original check dates. No orders placed.

Current dimensions, provenance and physical gates are in `parameters.json` and `test-record.json`. Older print/model folders and records are historical.

## Historical mount capture correction, 2026-10-04

Previous S17 print set: `first-prints/drivetrain-fit-2026-10-04`; seven-part review plate: `first-prints/bambu-capture-review-2026-10-04/Roller-300-first-fit-review.3mf`. The S18 rigid-drive files supersede these assembly sets; mounting corrections remain in current geometry.

Existing M3 hex pockets are AF6/depth2.8, for nominal AF5.5/height2.4 nuts. Load mouth and input-support nuts from the back face, with the carrier on the bench; load center-support nuts radially through the existing side ports. Hex flats prevent rotation; the installed screw retains the nut. Loose nuts are not snap-retained. Input caps now have local round OD9 bosses and OD6.2/depth3.2 head seats above the original1.5 mm cap floor. Screw seating planes and bearing stack positions are unchanged. Recessed screws remain removable; no captive-screw clip is claimed.

Fixed square roots that extended through the barrel are trimmed to the160 mm OD curve. The derived roof-open fixture inherits this native feature. At S17,1,625 history features,30 print bodies,167 drivetrain checks and122 mounting checks passed. Historical captures/checks remain in `design/mount-capture-2026-10-04`; current evidence is in `design/adversarial-review-2026-10-06`.

## Future control development

Preserve independent wheel drives and the removable actuator carrier. After mass, speed, duty and power are measured, require continuous velocity control, speed/position feedback, documented local current control or a fast current limit, temperature feedback and a communication watchdog.

An electronic differential commands appropriate different speeds during turns. Traction control also needs a vehicle-motion estimate; unequal wheel speeds alone do not prove slip. Jam detection uses current and speed feedback separately. Electronic protection cannot remove the first mechanical impact.

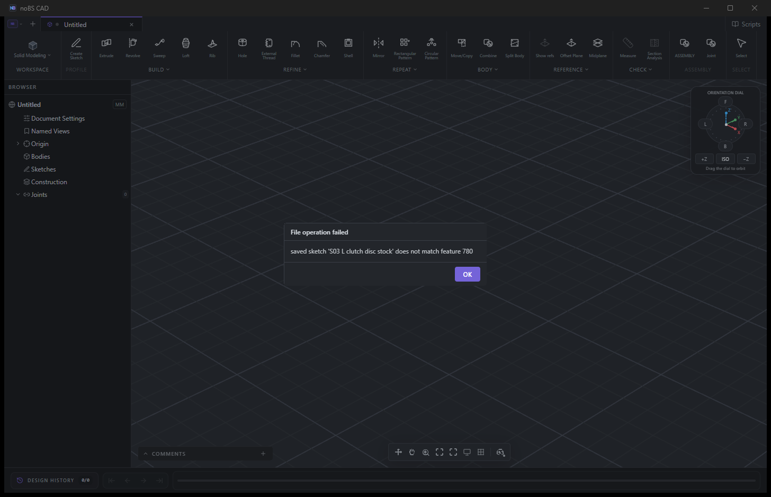
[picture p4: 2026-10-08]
design/empty-cad.png

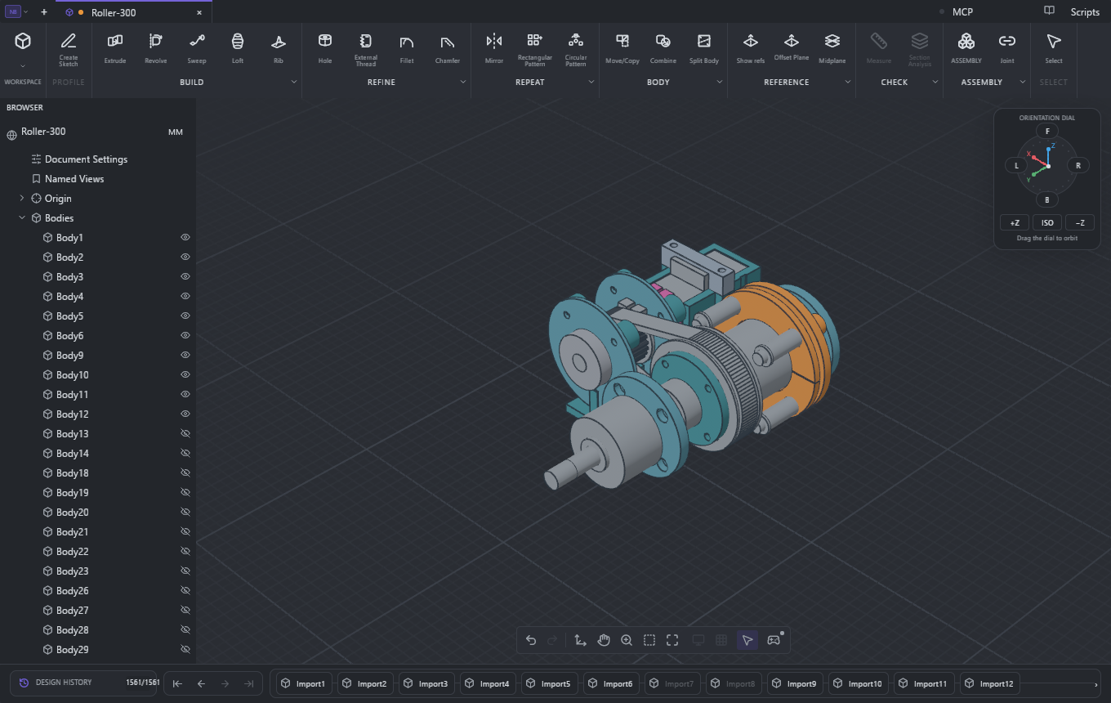
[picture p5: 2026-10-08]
design/drivetrain-stack-review-2026-10-04/one-drive-stack-native.png

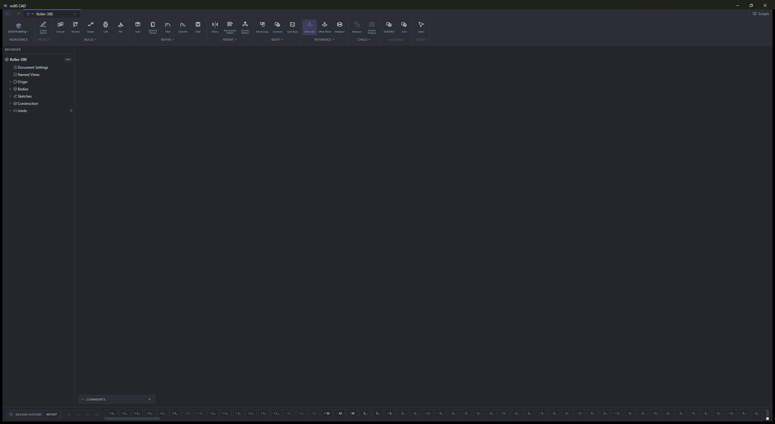
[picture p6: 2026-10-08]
design/cad-window.png

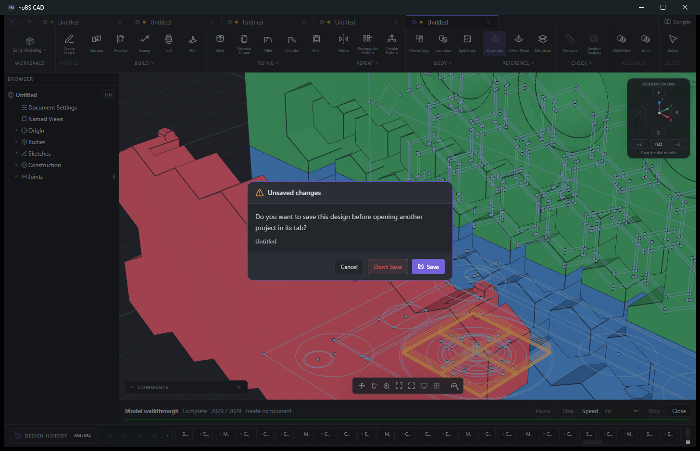
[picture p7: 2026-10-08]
design/cad-now.png

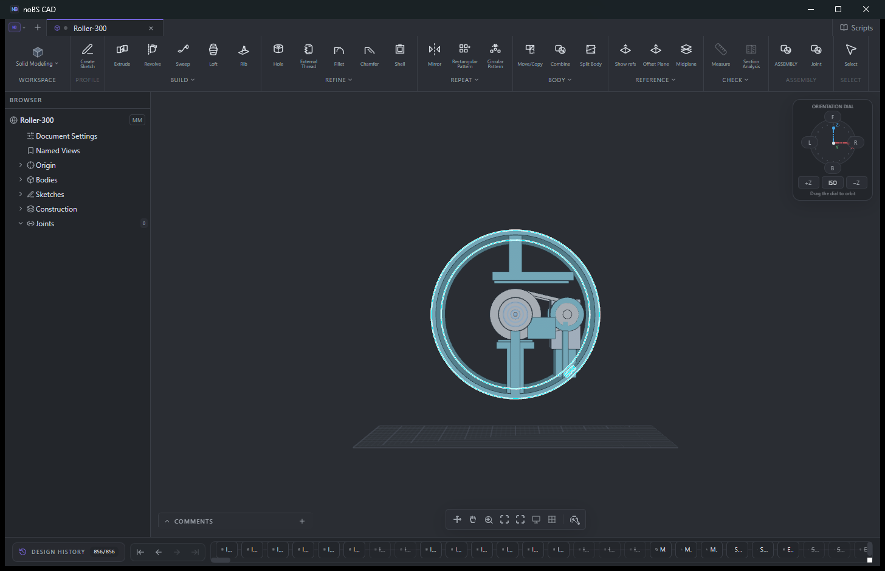
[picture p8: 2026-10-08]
design/built-open-front.png

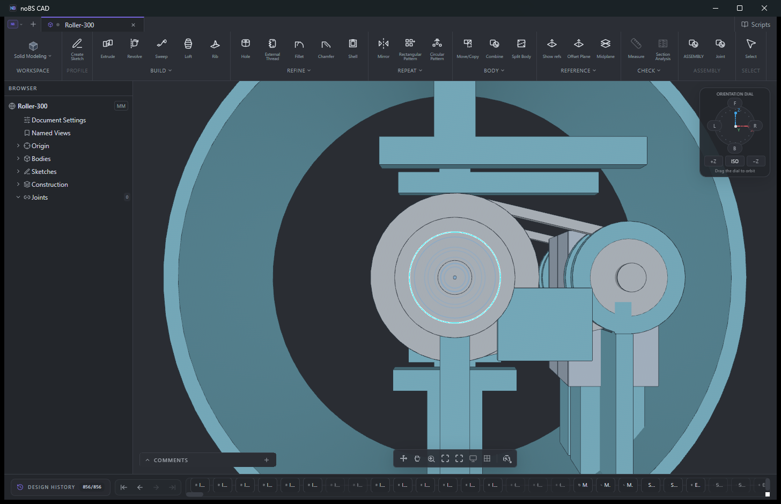
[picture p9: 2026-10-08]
design/built-open-close.png

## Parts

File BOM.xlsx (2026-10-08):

ROLLER-300 | FIRST INDOOR BUILD
S21 chassis fit / positive REX belt | PETG / 0.4 mm X2D | Unpowered ONE-drive fit; received hardware seating and endplay checks remain.
PRICED FIRST-PURCHASE SUBTOTAL |  |  |  | $100.12 | USD; partial subtotal excludes tax, shipping, filament and unresolved items. Included-kit rows are charged in H21.
Blue cells are editable quantities/prices. Blank Owned means unconfirmed; quantities are conservative shopping needs, not orders.
Buy qty = max(first target - owned - ordered, 0); packs round up. H21 covers H11 nuts. Retired clutch and input clamp rows have zero target quantities.
Source URLs are beside each row. Exact catalog sourcing does not qualify physical fit. Historical supplier references remain on retired/deferred rows.
ServoCity mechanics + Amazon belt/M3 kit. H08:16 M3x12 bearing screws/drive. H27:4 M3x10 servo-ear screws/drive; source/price check remains.
PRICED TWO-DRIVE PURCHASE SUBTOTAL |  |  |  | $173.59 | Credits confirmed owned/ordered quantities. Includes one additional servo; unpriced parts, prints and final electronics excluded.
ID | Part / exact model | Stage | Vehicle qty | First target | Owned | Ordered | Buy qty | Pack qty | Pack USD | Buy USD | Source | Checked | Reason / sizing / purchase gate | Group | Vehicle buy qty | Vehicle buy USD
M01 | Continuous-mode standard servo INJORA INJS035-360 | OWNED | 2 | 1 | 1 | 0 | 0 | 1 | $22.98 | $0.00 | https://www.amazon.com/dp/B0C9TM9X2C | 2026-10-04 | Owned continuous-rotation INJORA for first fit. Published25T/5.9mm spline; native case/ears use supplied drawing. Verify received seating and cable clearance. No external feedback. One additional servo needed for two drives; price retains its recorded offer date. | Actuator | 1 | $22.98
M02 | One shared servo programmer 3102-0001-0001 | SUPERSEDED | 0 | 0 | 0 | 0 | 0 | 1 | $12.99 | $0.00 | https://www.gobilda.com/servo-programmer-for-2000-series-dual-mode-servo/ | 2026-09-13 | Not required for owned INJORA servo. Do not order this programmer. | Actuator | 0 | $0.00
M03 | Accepted endless HTD3M belt D&D210-3M-09 / B00ISC4PHG | BUY ONE SIDE | 2 | 1 | 0 | 0 | 1 | 1 | $7.97 | $7.97 | https://www.amazon.com/dp/B00ISC4PHG | 2026-10-03 | D&D 210-3M-09: 210 mm pitch length, 70 teeth, 9 mm width. Main Amazon.com offer $7.97; stock shown, recheck at checkout. No delivery promise. | Transmission | 2 | $15.94
M04 | 8x22x7 radial bearing 1600-0722-0008 | BUY ONE SIDE | 8 | 4 | 0 | 0 | 4 | 2 | $3.99 | $7.98 | https://www.servocity.com/8mm-id-x-22mm-od-non-flanged-ball-bearing-2-pack/ | 2026-10-03 | Four each drive side. Confirm actual fit/drag on coupon; not a load rating. Purchased 608 batch must be checked against split seat and inner-race spacer contact. | Support | 8 | $15.96
M05 | 8mm round wheel clamp hub 1310-0016-0008 | BUY ONE SIDE | 2 | 1 | 0 | 0 | 1 | 1 | $7.99 | $7.99 | https://www.servocity.com/1310-series-hyper-hub-8mm-bore/ | 2026-10-06 | Exact Hyper Hub. S20 stock 6mm +2mm spacers, total8mm, Y105..113; D10 nominal manufacturer models. Rear hub abutment/endplay still needs receiving fit. | Support | 2 | $15.98
M06 | 8mm round clamp collar 2910-0921-0008 | BUY ONE SIDE | 2 | 1 | 0 | 0 | 1 | 1 | $4.99 | $4.99 | https://www.servocity.com/2910-series-aluminum-clamping-collar-8mm-id-x-21mm-od-9mm-length/ | 2026-10-03 | Inboard wheel collar Y85.8..94.8, 3 mm spacer Y94.8..97.8. Set measured endplay without bearing preload. | Support | 2 | $9.98
M07 | Wheel shaft, finished stock 2100-0008-0150; 8 x 150 mm | BUY FIT CHECK | 2 | 1 | 0 | 0 | 1 | 1 | $4.29 | $4.29 | https://www.servocity.com/8mm-x-150mm-stainless-steel-precision-shafting/ | 2026-10-03 | CURRENT: uncut 150 mm stock, Y8..158. Old 113 mm cutting instruction retired. Verify shaft diameter and journal fit. | Support | 2 | $8.58
M08 | Input REX shaft with factory Eclip 2106-4008-0480; 8mm REX x48, M4 tapped ends | BUY FIT CHECK | 2 | 1 | 0 | 0 | 1 | 1 | $4.29 | $4.29 | https://www.servocity.com/2106-series-stainless-steel-rex-shaft-8mm-diameter-48mm-length/ | 2026-10-06 | S20 actual manufacturer STEP. Nominal Y46.5..94.5; factory clip49.8..50.5. Positive AF7.3 printed bores drive both adapter and pulley. No input pinch screws or fabricated thin collar. | Support | 2 | $8.58
M09 | Bidirectional output slip limiter ComInTec00.25 DF d8 T1 | SUPERSEDED | 0 | 0 | 0 | 0 | 0 | 1 |  | $0.00 | https://www.comintec.com/download/cataloghi/sezioni/torque_limiters/DF_EN.pdf | 2026-09-13 | ComInTec limiter and subsequent custom spring clutch are retired. Current assembly uses the rigid belt drivetrain; no mechanical clutch purchase. | Transmission | 0 | $0.00
M10 | Ground metal drive plates / bushes Supplier prepared to00.25 DF | SUPERSEDED | 0 | 0 | 0 | 0 | 0 | 1 |  | $0.00 |  | 2026-09-13 | ComInTec plates, reaction plates and friction lining are retired. No current assembly or purchase requirement. | Transmission | 0 | $0.00
M11 | Printed servo bridge and positive REX horn adapter S20; H25T horn + AF7.3 keyed input | PRINT FIT | 2 | 0 | 0 | 0 | 0 | 1 |  | $0.00 | Local CAD + design/vendor/servo-horn-1906-0025-0032/source.json | 2026-10-06 | Native shared datums repaired, four servo ear and two bridge nuts captured. Adapter has factory Eclip pocket/radial window; two input friction clamps removed. Printed pieces counted in current print-set manifest/material estimate. | Transmission | 2
P01 | Printed positive REX input and rigid output pulleys 24T /48T, 3M pitch, 9mm belt | PRINT FIT | 4 | 2 | 0 | 0 | 2 | 1 |  |  | Local native CAD: Roller-300.nbcad | 2026-10-06 | S20 positive AF7.3 input bore replaces friction clamp. Integral R5.5 input lands locate pulley between bearing inner races with0.4mm total nominal endplay. Output bolts to purchased Sonic hub. No mechanical torque limiter. | Printed | 4
P02 | One rigid wheel print S21 open-face rigid wheel;230mm rim,40mm width,4mm hub web;246mm only with provisional tread | HOLD WHEEL FIT | 2 | 1 | 0 | 0 | 1 | 1 |  |  | Local native CAD: Roller-300.nbcad | 2026-10-07 | S21 open faces insideR108 preserve4mm hub web,bolt pattern and D230x40 rim while exposing wheel-hub screws and support cleanup. Fresh outboard-down native X2D PETG slice:336.71g including supports,8.64h; no warnings. Receiving fit and support cleanup still precede this print. Strength/tread deferred. | Printed | 2
P03 | Single shell-first barrel housing and structural hatch Fresh native S02/S03 geometry; D160x210; no legacy frame | HOLD BARREL | 1 | 0 | 0 | 0 | 0 | 1 |  | $0.00 | Local native CAD: Roller-300.nbcad | 2026-10-03 | Whole shell/hatch deferred. Current first article uses the roof-open one-drive section; rear driver access in whole frame remains unresolved. | Printed | 1
P04 | Bearing fit coupon 22.05/22.15/22.25 holes | HOLD GAUGE | 1 | 1 | 0 | 0 | 1 | 1 |  |  | Local native CAD: Roller-300.nbcad | 2026-10-03 | Historical bearing gauge only. Do not mistake it for current split-seat fit proof; current retainers tested on one-drive fixture. | Printed | 1
P05 | Servo fit gauge Selected25-2 mounting frame | SUPERSEDED | 0 | 0 | 0 | 0 | 0 | 1 |  | $0.00 | Local native CAD: Roller-300.nbcad | 2026-09-13 | goBILDA25-2 gauge does not establish owned INJORA fit. Do not print for this servo. | Printed | 0 | $0.00
H01 | Major M4 bolts, captive nuts, washers Consistent metric family | HOLD REMAINDER |  | 0 |  | 0 | 0 | 1 |  | $0.00 |  | 2026-09-13 | Specific new housing fasteners itemized below. Remaining component restraints and washers still unresolved; no complete fastener kit claimed. | Hardware
E01 | Small3-cell battery Owned, identity/dimensions pending | OWNED | 1 | 0 | 1 | 0 | 0 | 1 |  | $0.00 |  | 2026-09-13 | Measure body and lead/plug envelope plus mass;90x85x30 box is not measured. | Owned | 0 | $0.00
E02 | Original Pixracer Owned original | OWNED | 1 | 0 | 1 | 0 | 0 | 1 |  | $0.00 |  | 2026-09-13 | Case, cable/plug profile and mounting must be measured; installation allowance60x60x35. | Owned | 0 | $0.00
E03 | Pi Zero with Wi-Fi Owned variant pending | OWNED | 1 | 0 | 1 | 0 | 0 | 1 |  | $0.00 |  | 2026-09-13 | Bare board nominal65x30x5; headers/case/mated plugs separate. No visible camera owned. | Owned | 0 | $0.00
S01 | Front distance modules ACEIRMC TOF400C/B0DC6M6G7W | OWNED | 4 | 0 | 4 | 0 | 0 | 4 |  | $0.00 | https://www.amazon.com/dp/B0DC6M6G7W | 2026-09-13 | User confirmed four TOF400C modules owned on2026-10-04. No new camera/module purchase. Full hood/solder/depth and cable envelopes still require fit checks. | Sensors | 0 | $0.00
S02 | Forward thermal camera TOPDON TC002C Duo | OWNED | 1 | 0 | 1 | 0 | 0 | 1 |  | $0.00 | https://www.amazon.com/dp/B0F8MZVFBJ | 2026-10-03 | User confirmed TOPDON TC002C Duo owned on2026-10-04. No replacement purchase. Verify mated extension, lens center and physical fit. | Sensors | 0 | $0.00
S03 | Forward visible camera Not selected / not owned | HOLD | 1 | 0 | 0 | 0 | 0 | 1 |  | $0.00 |  | 2026-09-13 | Select exact camera/lens before solid and aperture. No guessed envelope. | Sensors | 1
S04 | Future wheel motion readers and targets Exact hardware pending | HOLD | 2 | 0 | 0 | 0 | 0 | 1 |  | $0.00 |  | 2026-09-13 | Deferred control development. One wheel encoder per side can support speed control; traction estimation also needs vehicle-motion information. | Sensors | 2
S05 | Mechanical clutch slip comparison readers Needed with non-feedback servo | RETIRED CLUTCH | 0 | 0 | 0 | 0 | 0 | 1 |  | $0.00 |  | 2026-09-13 | Separate before/after-clutch reader pair is unnecessary with rigid belt drive. Future bus-actuator feedback is evaluated with the controller upgrade. | Sensors | 0 | $0.00
H02 | Battery straps / harness / strain relief Exact sizes pending | HOLD |  | 0 |  | 0 | 0 | 1 |  | $0.00 |  | 2026-09-13 | Wiring is a physical part of package. Use soldered sensor pigtails with remote removable connectors as starting route. | Hardware
H03 | Charging contacts and retained panel Two contacts; product pending | HOLD | 2 | 0 | 0 | 0 | 0 | 1 |  | $0.00 |  | 2026-09-13 | Rear/lower accessible inset panel; spring travel, recess and purchased contact size pending. Electrical charging design deferred. | Hardware | 2
E04 | Power and protection hardware Products intentionally deferred | HOLD |  | 0 |  | 0 | 0 | 1 |  | $0.00 |  | 2026-09-13 | Actuator disconnect, protection, separate branches and charge hardware must eventually fit. Not counted as zero mass or zero cost. | Electronics
H04 | Wheel-to-hub socket screws M4x10, ISO4762 / goBILDA2800-0004-0010 | HOLD PRICE | 8 | 4 |  | 0 | 4 | 1 |  |  | https://www.servocity.com/m4-x-0-7mm-zinc-plated-socket-head-screw-10mm-length/?sku=2800-0004-0010 | 2026-10-03 | Exact 2800-0004-0010 catalog candidate. Pack/price not exposed by current variant page; verify before ordering. Four wheel hub screws per drive, nominal 6 mm engagement. | Wheel hardware | 8
H05 | Recessed bead-retainer socket screws M4x35 ISO4762; Accu SSC-M4-35-A2-R360 reference | HISTORICAL | 0 | 0 |  | 0 | 0 | 1 |  | $0.00 | https://www.accu.co.uk/metric-cap-head-screws/250081-SSC-M4-35-A2-R360 | 2026-09-13 | Superseded three-piece wheel/bead concept; retained record only. No current purchase. | Wheel hardware | 0 | $0.00
H06 | Captured wheel bead-retainer nuts M4x0.7 ISO4032 plain hex;7 mm AF,3.2 mm thickness reference | HISTORICAL | 0 | 0 |  | 0 | 0 | 1 |  | $0.00 |  | 2026-09-13 | Superseded three-piece wheel/bead concept; retained record only. No current purchase. | Wheel hardware | 0 | $0.00
P06 | Removable input carriage and bearing-cap set S20 carrier, roof-open section,4 retainers,servo bridge and positive REX horn adapter | PRINT FIT | 2 | 1 | 0 | 0 | 1 | 1 |  |  | Local native CAD: Roller-300.nbcad | 2026-10-06 | Eight support/interface prints per one-drive fit article: section,carrier,four retainers,bridge,adapter. P01 supplies two pulleys and P02 the wheel, for11 unique pieces total. Four servo-ear and two bridge nut captures; rounded posts and lower driver passages. | Printed drive | 2
H07 | Structural hatch screws M4x12 countersunk 90deg candidate | HOLD BARREL | 8 | 0 |  | 0 | 0 | 1 |  | $0.00 |  | 2026-09-19 | Whole-frame hatch deferred; exact product remains unselected. No first-drive order. | Shell fasteners | 8
H08 | M3x12 bearing-retainer screws iexcell B08B1W1FHS; M3x0.5 socket head,12 mm | BUY FIT CHECK | 32 | 16 |  | 0 | 16 | 100 | $8.26 | $8.26 | https://www.amazon.com/dp/B08B1W1FHS | 2026-10-04 | 100-pack replaces six-packs. Recorded listing head D5.50 x2.93mm,12mm thread,2.5mm hex, grade12.9 alloy steel/black oxide. Sixteen bearing-retainer screws per drive. Current servo ears use four M3x10 screws per drive, separately H27. Verify received head/seat dimensions; PETG preload remains limited. | Shell fasteners | 32 | $8.26
H09 | Carrier tension screws 2802-0004-0014; M4x0.7 button head,14 mm | BUY FIT CHECK | 6 | 3 |  | 0 | 3 | 25 | $3.69 | $3.69 | https://www.servocity.com/2802-series-zinc-plated-steel-button-head-screw-m4-x-0-7mm-14mm-length-25-pack/ | 2026-10-03 | Three per carrier; exact active geometry. Use 9x4.3x0.8 washers H19 and M4 plain nuts H12. Physical receiving check remains. | Shell fasteners | 6 | $3.69
H10 | Input bearing-cap screws M3x30 socket-head candidate | SUPERSEDED | 0 | 0 |  | 0 | 0 | 1 |  | $0.00 |  | 2026-09-19 | Old M3x30 input-cap candidate retired. Active standalone retainers use M3x12; counts consolidated in H08. | Shell fasteners | 0 | $0.00
H11 | All active M3 plain captive nuts M3x0.5 plain hex; kit includes150 | INCLUDED KIT | 44 | 22 |  | 0 | 22 | 150 |  |  | https://www.amazon.com/dp/B0GV4G5DNP | 2026-10-06 | 22 per drive: bearing retainers16 + servo ears4 + upper bridge2. Both input pinch nuts retired. Plain M3 nuts in H21; native pockets tested with AF5.5 x2.4 nominal hardware. | Shell fasteners | 44
H12 | Carrier and deferred hatch M4 plain nuts 2811-0004-0007; M4x0.7,7 mm hex | BUY FIT CHECK | 14 | 3 |  | 0 | 3 | 25 | $2.49 | $2.49 | https://www.servocity.com/2811-series-zinc-plated-steel-hex-nut-m4-x-0-7mm-7mm-hex-25-pack/ | 2026-10-03 | Current carrier3 per drive + deferred hatch8 per vehicle. Wheel/input retainers now use M3. Verify actual nut height3.2 mm and pocket fit. | Shell fasteners | 14 | $2.49
M12 | Inboard bearing inner-race spacer 1522-0010-0030;8 ID x10 OD x3 mm | BUY FIT CHECK | 2 | 1 |  | 0 | 1 | 4 | $2.99 | $2.99 | https://www.servocity.com/1522-series-8mm-id-spacer-10mm-od-3mm-length-4-pack/ | 2026-10-03 | Published nominal dimensions; steel0.62 g each. Received tolerance and endplay verification remain. Price observed, stock/delivery not guaranteed; no purchase made. | Wheel retention | 2 | $2.99
M13 | Outboard wheel retention spacer 1529-0012-0100;8 ID x12 OD x10 mm | SUPERSEDED | 0 | 0 |  | 0 | 0 | 4 | $1.99 | $0.00 | https://www.gobilda.com/8mm-id-steel-spacer-12mm-od-10mm-length-4-pack/ | 2026-09-19 | Historical10mm output spacer retired. Current output stop is stock6mm M18 plus2mm M20, D10/ID8, total8mm. | Wheel retention | 0 | $0.00
M14 | Outboard inner-race shim 2807-0811-0500;8 ID x11 OD x0.5 mm | SUPERSEDED | 0 | 0 |  | 0 | 0 | 12 | $2.69 | $0.00 | https://www.gobilda.com/2807-series-stainless-steel-shim-8mm-id-x-11mm-od-0-50mm-thickness-12-pack/ | 2026-09-19 | Historical outboard wheel0.5mm shim retired. Current input rear shim is0.5mm M19; the old1.7mm stack is retired. | Wheel retention | 0 | $0.00
H13 | Removable servo restraint straps 8 mm width candidate; length measured after horn/ear check | SUPERSEDED | 0 | 0 |  | 0 | 0 | 1 |  | $0.00 |  | 2026-09-19 | Servo restraint straps retired. Current bridge uses two M3x16 pan screws H17, and servo ears use four M3x10 socket screws H27 per drive. | Shell fasteners | 0 | $0.00
M15 | Metal servo horn 1906-0025-0032;25T,32 mm | BUY FIT | 2 | 1 |  | 0 | 1 | 1 | $4.99 | $4.99 | https://www.servocity.com/1906-series-lightweight-servo-hub-25-tooth-spline-32mm-diameter/ | 2026-10-06 | Official STEP integrated into both drives. Nominal H25T/5.9mm INJORA interface; verify seating and retaining screw by hand. Manufacturer drawing and STEP have differing pilot dimensions: adapter clearance accommodates both. | Drivetrain | 2 | $9.98
M16 | Rigid output shaft clamping hub 1309-0016-0008;8 mm Sonic Hub | BUY FIT CHECK | 2 | 1 |  | 0 | 1 | 1 | $7.99 | $7.99 | https://www.servocity.com/1309-series-sonic-hub-8mm-bore/ | 2026-10-03 | Existing metal Sonic hub moved beside 48T pulley, mounting face |Y|65.25. Four recessed M4x16 screws; nominal6.2mm engagement. Verify pilot, clamp and threads on receipt. | Drivetrain | 2 | $15.98
M17 | Clutch compression springs 2916-0001-0002;8 OD/6 ID,25 free length | RETIRED CLUTCH | 0 | 0 |  | 0 | 0 | 2 | $3.99 | $0.00 | https://www.servocity.com/compression-spring-6mm-id-x-8mm-od-2-3kg-max-load-16-25mm-length-2-pack/ | 2026-10-03 | Retired by approved rigid belt drive on 2026-10-05. No current print or purchase requirement. | Drivetrain | 0 | $0.00
M18 | Input and output inner-race metal spacers, 6mm 1522-0010-0060; 8ID x10OD x6; 4-pack | BUY FIT CHECK | 4 | 2 |  | 0 | 2 | 4 | $3.49 | $3.49 | https://www.servocity.com/1522-series-8mm-id-spacer-10mm-od-6mm-length-4-pack/ | 2026-10-06 | One input rear spacer Y88..94 and one output mouth spacer Y105..111 per drive. Stock manufacturer STEP replaces the unsourced 6mm clamp collar. One four-pack covers both drives. | Drivetrain | 4 | $3.49
M19 | Input rear metal shim, 0.5mm 2807-0811-0500; 8ID x11OD x0.5; 12-pack | BUY FIT CHECK | 2 | 1 |  | 0 | 1 | 12 | $2.69 | $2.69 | https://www.servocity.com/2807-series-stainless-steel-shim-8mm-id-x-11mm-od-0-50mm-thickness-12-pack/ | 2026-10-06 | One per drive Y94..94.5. Actual manufacturer STEP; old unsourced 1.7mm stack retired. Receiving endplay checked before tightening; no outer-race preload. | Drivetrain | 2 | $2.69
M20 | Output mouth metal spacer, additional 2mm 1522-0010-0020; 8ID x10OD x2; 4-pack | BUY FIT CHECK | 2 | 1 |  | 0 | 1 | 4 | $2.79 | $2.79 | https://www.servocity.com/1522-series-8mm-id-spacer-10mm-od-2mm-length-4-pack/ | 2026-10-06 | Y111..113, together with M18 output 6mm spacer forms the required 8mm stop. Actual manufacturer STEP. Supersedes unsourced 11OD x8 spacer; avoids the ambiguous 8mm product URL currently labeled 9mm. | Drivetrain | 2 | $2.79
H14 | Rigid output pulley mounting screws 2802-0004-0016; M4x0.7 button head,16mm | BUY FIT CHECK | 8 | 4 |  | 0 | 4 | 25 | $3.79 | $3.79 | https://www.servocity.com/2802-series-zinc-plated-steel-button-head-screw-m4-x-0-7mm-16mm-length-25-pack/ | 2026-10-05 | Four per drive. Replaces M4x8 clutch screws. D8/depth4.7 counterbores; screw seats |Y|75.05; nominal6.2mm metal thread engagement. Bench-assemble before insertion into stationary bearings. | Drivetrain | 8 | $3.79
H15 | Input pulley/coupler pinch screws 2800-0003-0010;M3x0.5 socket head,10 mm | RETIRED INPUT CLAMP | 0 | 0 |  | 0 | 0 | 6 | $3.19 | $0.00 | https://www.servocity.com/zinc-plated-steel-socket-head-screw-m3-x-0-5mm-10mm-length-6-pack/ | 2026-10-06 | S20 positive REX shaft removes both input pinch screws and nuts. Do not order for the active drivetrain. | Drivetrain | 0 | $0.00
H16 | Clutch adjuster screws M3x0.5 socket head,35 mm;25 in kit | RETIRED CLUTCH | 0 | 0 |  | 0 | 0 | 1 |  | $0.00 | https://www.amazon.com/dp/B0GV4G5DNP | 2026-10-03 | Retired by approved rigid belt drive on 2026-10-05. No current print or purchase requirement. | Drivetrain | 0 | $0.00
H17 | Servo bridge through screws 632296; M3x0.5 pan head16mm, Phillips #1; 6-pack | BUY FIT CHECK | 4 | 2 |  | 0 | 2 | 6 | $1.99 | $1.99 | https://www.servocity.com/3mm-x-16mm-zinc-plated-metric-pan-head-phillips-machine-screws/ | 2026-10-06 | Two per drive. Through-hole and side-loaded AF6 captured nuts at Z128.7..131.5. Bolt seat143.25, tip127.25; full nominal nut engagement. Unrecessed head D6 x2.5 clearance envelope; check received head and driver. | Drivetrain | 4 | $1.99
H18 | Clutch captive locking nuts M3x0.5 nyloc; pocket fit to verify | RETIRED CLUTCH | 0 | 0 |  | 0 | 0 | 1 |  | $0.00 |  | 2026-10-03 | Retired by approved rigid belt drive on 2026-10-05. No current print or purchase requirement. | Drivetrain | 0 | $0.00
H19 | Carrier metal washers DIN125 M4;9 OD x4.3 ID x0.8 thick | HOLD SOURCE | 6 | 3 |  | 0 | 3 | 1 |  |  |  | 2026-10-03 | Amazon preferred; exact listing pending. ServoCity4x8 washer differs from modeled9x4.3x0.8; no silent replacement. | Drivetrain | 6
H20 | Clutch spring guide tubes Metal5 OD x3.2 ID x16 long | RETIRED CLUTCH | 0 | 0 |  | 0 | 0 | 1 |  | $0.00 |  | 2026-10-03 | Retired by approved rigid belt drive on 2026-10-05. No current print or purchase requirement. | Drivetrain | 0 | $0.00
H21 | Shared long M3 hardware kit Kernmax600pcs;B0GV4G5DNP | BUY FIT CHECK | 1 | 1 |  | 0 | 1 | 1 | $8.98 | $8.98 | https://www.amazon.com/dp/B0GV4G5DNP | 2026-10-03 | One kit charged once for the plain M3 nuts H11; 22 per drive. Bridge uses separately sourced M3x16 pan screws H17. Long screws in this kit are spare; use existing compatible plain nuts if already owned and credit the quantity. | Drivetrain | 1 | $8.98
H22 | Clutch spring metal washers 9 OD x3.2 ID x1 thick | RETIRED CLUTCH | 0 | 0 |  | 0 | 0 | 1 |  | $0.00 |  | 2026-10-03 | Retired by approved rigid belt drive on 2026-10-05. No current print or purchase requirement. | Drivetrain | 0 | $0.00
M21 | Trial friction lining set 0.5 mm;front44/27.4 annulus,rear2 halves44/33.4 | RETIRED CLUTCH | 0 | 0 |  | 0 | 0 | 1 |  | $0.00 |  | 2026-10-03 | Retired by approved rigid belt drive on 2026-10-05. No current print or purchase requirement. | Drivetrain | 0 | $0.00
H23 | Servo center retention screw M3 low-profile button head, D5.7 x1.65mm; length verified on servo | RECEIVING FIT | 2 | 1 |  | 0 | 1 | 1 |  |  | https://www.injora.com/products/injora-injs035-360-35kg-waterproof-digital-servo-360-steering-winch-wheel-for-rc | 2026-10-06 | Use a compatible low-profile center screw from servo/horn hardware if it seats without bottoming. Head seatY43.6; D5.7 x1.65 head ends45.25; nominal shaft begins46.5 (1.25mm gap, conservative vendor STEP gap0.883mm). Length/thread depth remain a receiving check. Install before input shaft. | Drivetrain | 2
H24 | Horn-to-adapter mounting screws 2802-0004-0006; M4x0.7 button head,6mm | BUY FIT | 8 | 4 | 0 | 0 | 4 | 25 | $2.99 | $2.99 | https://www.servocity.com/2802-series-zinc-plated-steel-button-head-screw-m4-x-0-7mm-6mm-length-25-pack/ | 2026-10-06 | Four per drive. M4x6 ISO7380-1 heads atY45.1..47.3; nominal metal engagement2.5mm into the purchased horn. Driver access checked on bench. Positive REX replaces pinch, with factory Eclip insertion through adapter side window. | Drivetrain | 8 | $2.99
P07 | Final flexible wheel tread set TPU;246 mm overall diameter provisional | HOLD TREAD | 2 | 0 | 0 | 0 | 0 | 1 |  | $0.00 | Local native CAD: Roller-300.nbcad | 2026-10-04 | Full-vehicle tread/material/bonding and bead retention remain unqualified. Omitted from the rigid-wheel unpowered fit article; not zero cost. | Printed | 2
H25 | Input REX end-retention screw 2802-0004-0008; M4x0.7 button head8mm;25-pack | BUY FIT CHECK | 2 | 1 |  | 0 | 1 | 25 | $3.19 | $3.19 | https://www.servocity.com/2802-series-zinc-plated-steel-button-head-screw-m4-x-0-7mm-8mm-length-25-pack/ | 2026-10-06 | One per drive; washer thickness1.5 leaves nominal6.5mm M4 engagement. Actual manufacturer STEP. Tighten against shaft end and metal stack, checking free rotation/endplay. Thread phase in CAD is a reference, not a measured thread fit. | Drivetrain | 2 | $3.19
H26 | Input end-retention steel washer 2801-0004-0011; 4ID x11OD x1.5;25-pack | BUY FIT CHECK | 2 | 1 |  | 0 | 1 | 25 | $2.29 | $2.29 | https://www.servocity.com/2801-series-zinc-plated-steel-washer-4mm-id-x-11mm-od-25-pack/ | 2026-10-06 | One per drive Y94.5..96.0; actual manufacturer STEP, OD10.9. End screw and washer retain rear spacer/shim on the bearing inner race; front Eclip is captured in the printed adapter. | Drivetrain | 2 | $2.29
H27 | Servo-ear mounting screws M3x0.5 socket head,10mm;2800-0003-0010 historical catalog reference | HOLD SOURCE | 8 | 4 |  | 0 | 4 | 6 |  |  | https://www.servocity.com/zinc-plated-steel-socket-head-screw-m3-x-0-5mm-10mm-length-6-pack/ | 2026-10-06 | Four M3x10 per drive, matching current S20 ear stack and assembly plan. Reuses an existing catalog reference formerly attached to retired pinch screws. Price, pack and current availability have not been freshly verified. Check received socket-head envelope, actual thread engagement and servo grommet/eyelet fit. H08 M3x12 screws are for bearing retainers. | Drivetrain | 8
PRINT MATERIAL ESTIMATE | ONE UNPOWERED DRIVE | CONSUMED MATERIAL, NOT SPOOL PURCHASE COST
Reference ten-part fit plate incl. supports (kg) |  |  |  | 0.294 | Corrected complete one-drive plate reference. Remove already-printed fit pieces before arranging and reslicing the remaining parts.
Current native wheel slice incl. supports (kg) |  |  |  | 0.337 | Current native wheel exported by CAD, placed rigidly and sliced offline in Bambu Studio.
Filament USD/kg - editable assumption |  |  |  | $25.00 | $25/kg is a budgeting assumption, not a supplier quote. Own filament is not credited here.
Estimated consumed material USD |  |  |  | $15.77 | Excludes tread, calibration waste, failed prints and electricity. Actual staged support mass depends on final plate layout.
FULL ROBOT TOTAL REMAINS UNRESOLVED: partial two-drive subtotal is not a complete vehicle quote.
Unresolved: carrier washers, wheel fasteners, servo-ear M3x10 source/price, center-screw length and final tread. Shaft retention uses stock parts.
Thermal camera and four ToF modules owned; visible camera, wheel feedback, wiring, power protection and charging hardware remain deferred.
Rigid belt drive has no mechanical torque limiter. Verify received horn seating, screw engagement and shaft retention before supervised powered tests.

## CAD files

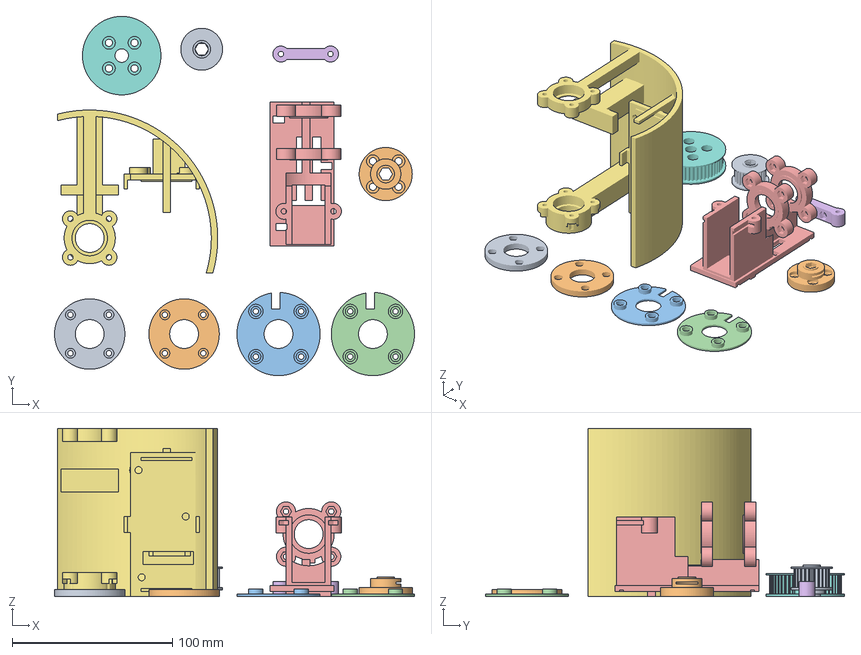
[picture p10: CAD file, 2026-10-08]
first-prints/corrected-full-fit-2026-10-06/corrected-full-fit-placement.3mf
225.0 x 224.5 x 105.0 mm
mouth-bearing-retainer
center-bearing-retainer
input-inboard-bearing-retainer
input-outboard-bearing-retainer
input-sliding-carrier
servo-upper-bridge
one-drive-fit-section
rigid-output-pulley
input-rex-pulley
servo-horn-rex-adapter

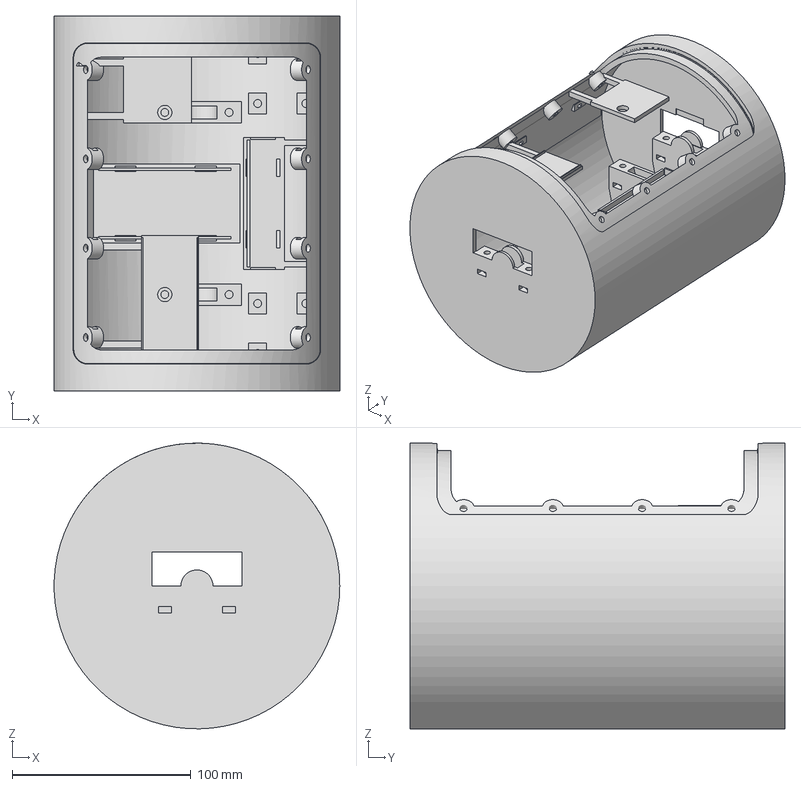
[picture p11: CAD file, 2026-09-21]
first-prints/native-port/main-shell.3mf
159.9 x 210.0 x 160.0 mm

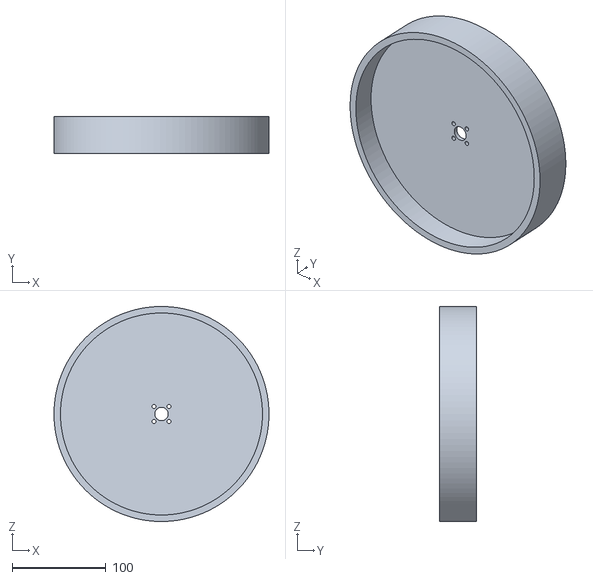
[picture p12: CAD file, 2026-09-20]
first-prints/shell-first-review/left-wheel-assembly-coordinates.stl
230.0 x 40.0 x 230.0

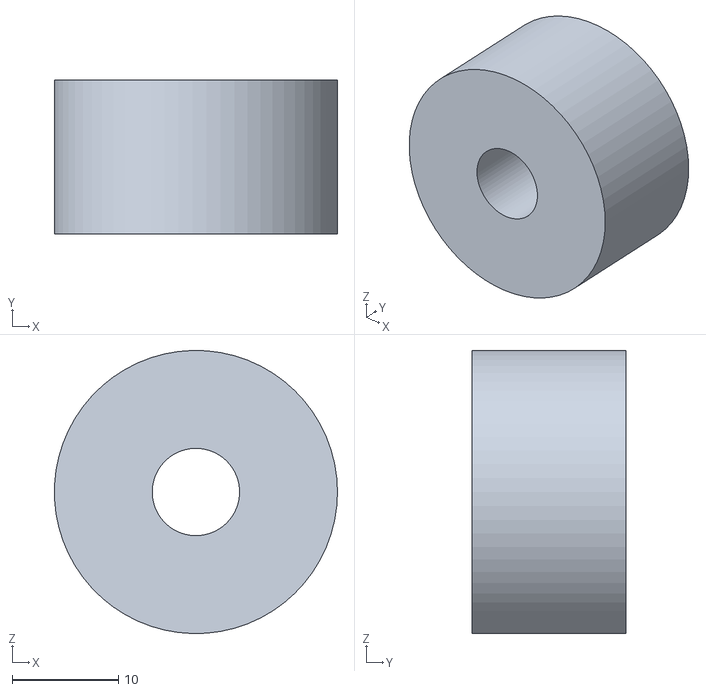
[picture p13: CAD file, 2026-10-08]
first-prints/drive-unit/output-pulley-shaft-sleeve-assembly.stl
26.6 x 14.5 x 26.6

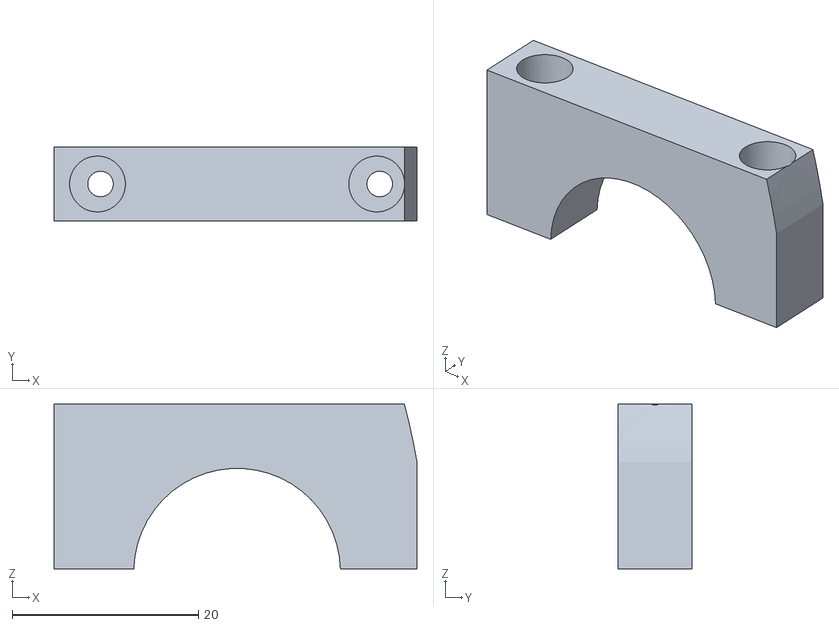
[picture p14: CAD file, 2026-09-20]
first-prints/shell-first-review/input-cap-inner-assembly-coordinates.stl
39.0 x 8.00 x 17.7

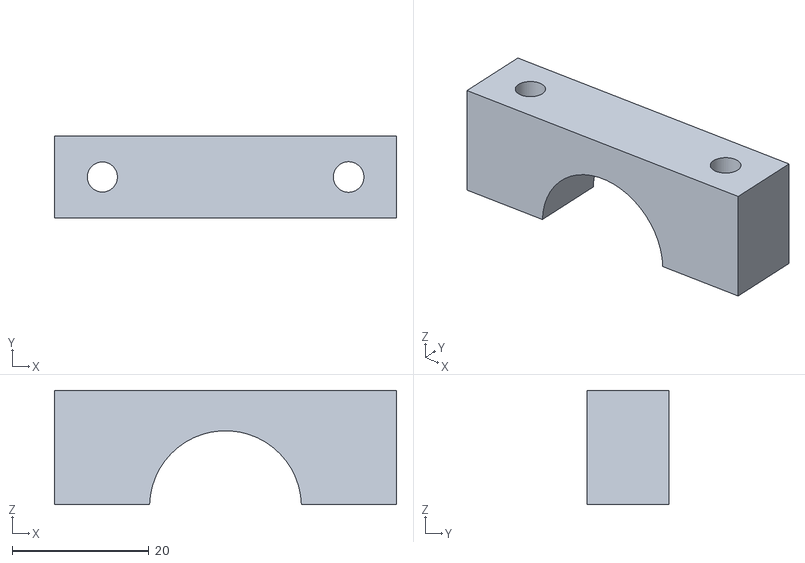
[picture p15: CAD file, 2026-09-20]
first-prints/shell-first-review/wheel-cap-inner-assembly-coordinates.stl
50.0 x 12.0 x 16.7

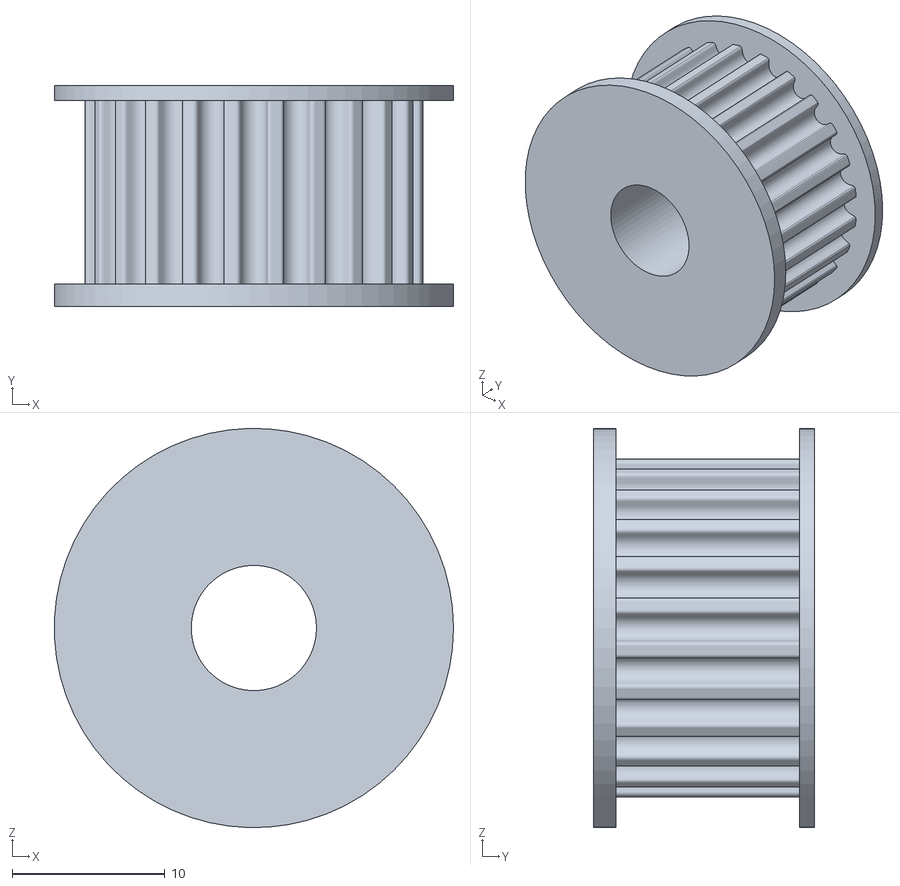
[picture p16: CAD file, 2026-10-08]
first-prints/drive-unit/input-pulley-24t-assembly.stl
26.1 x 14.5 x 26.1

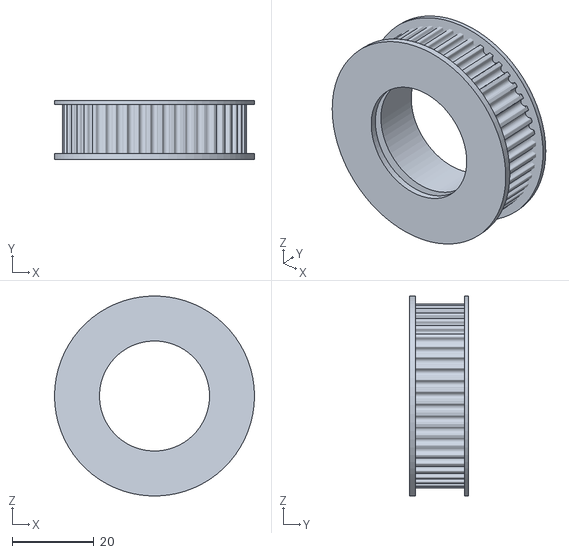
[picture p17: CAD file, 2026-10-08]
first-prints/drive-unit/output-pulley-48t-assembly.stl
49.1 x 14.5 x 49.0

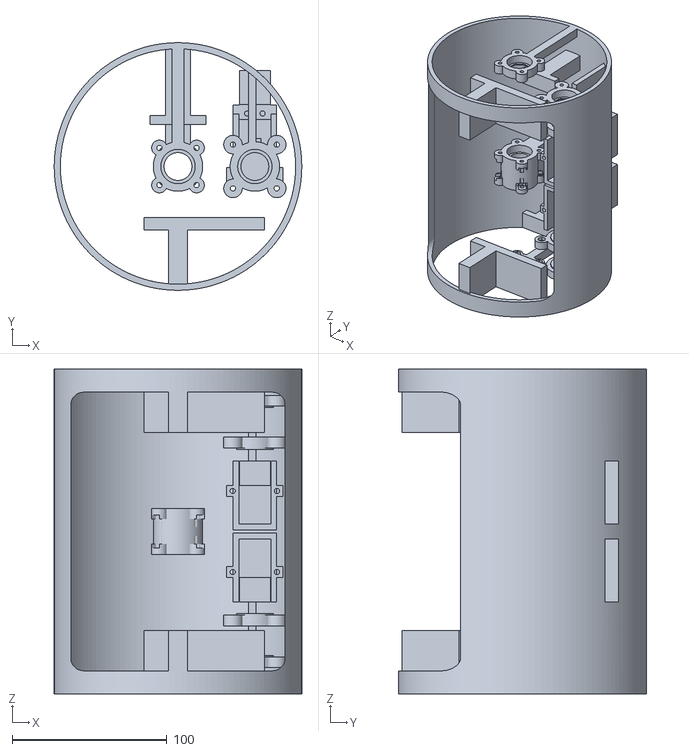
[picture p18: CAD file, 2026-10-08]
first-prints/native-fit-2026-10-03/main-shell-axle-vertical.stl
160.0 x 160.0 x 210.0

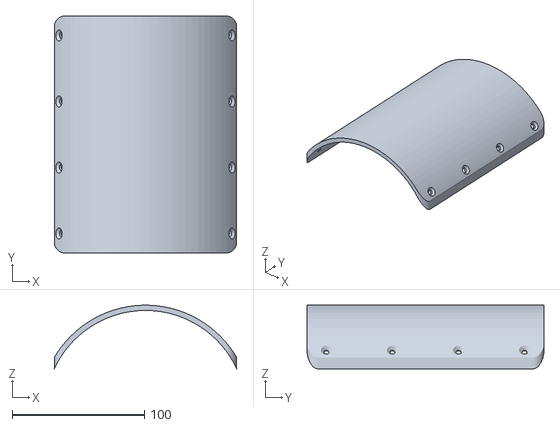
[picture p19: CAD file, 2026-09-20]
first-prints/shell-first-review/curved-hatch-assembly-coordinates.stl
138.0 x 179.4 x 48.1

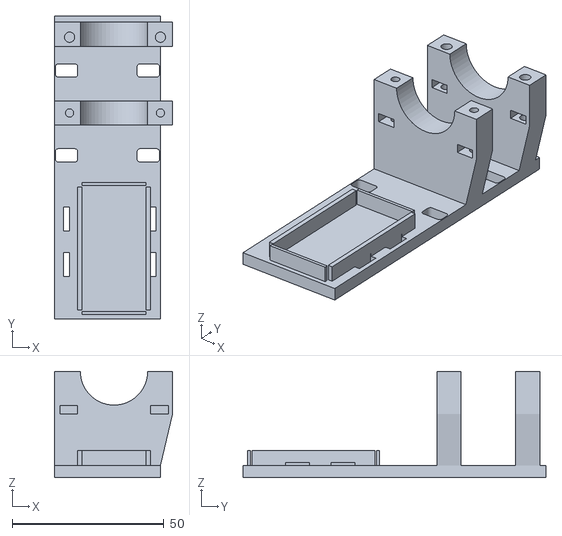
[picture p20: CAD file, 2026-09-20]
first-prints/shell-first-review/left-input-carriage-assembly-coordinates.stl
39.0 x 100.0 x 35.0

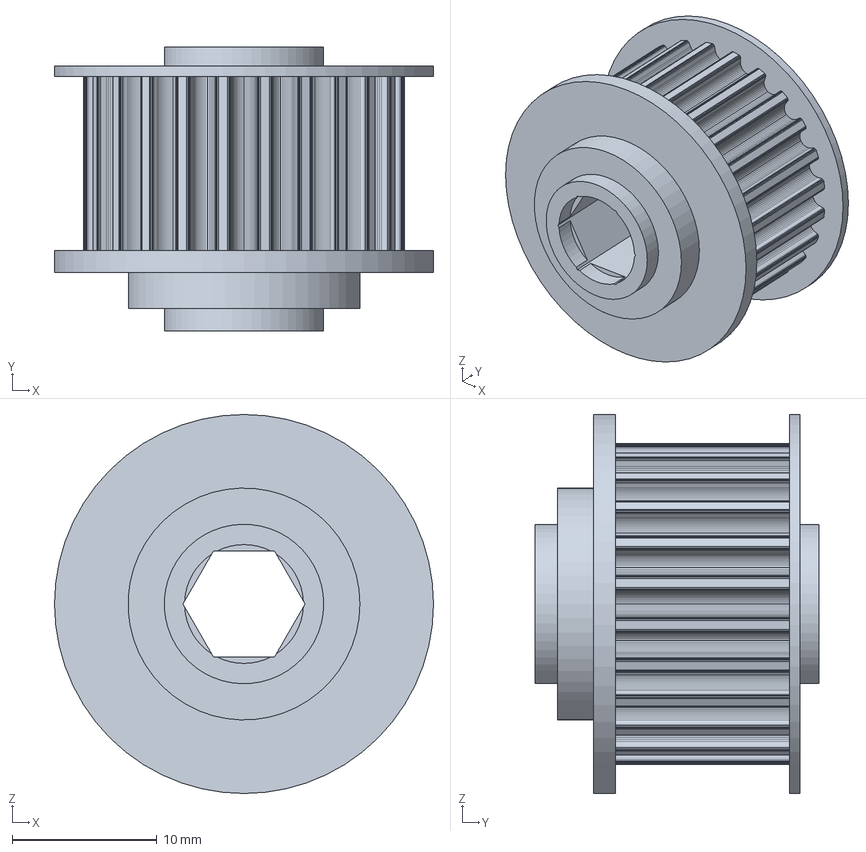
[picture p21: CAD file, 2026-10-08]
design/adversarial-review-2026-10-06/body-10.step
26.2 x 19.6 x 26.2 mm

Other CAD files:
first-prints/corrected-full-fit-2026-10-06/Roller-300-full-fit-corrected.3mf
first-prints/shell-first-review/wheel-cap-outer-assembly-coordinates.stl
first-prints/shell-first-review/main-shell-assembly-coordinates.stl
first-prints/shell-first-review/input-cap-outer-assembly-coordinates.stl
first-prints/shell-first-review/main-shell-axle-vertical.stl
first-prints/drive-unit/main-shell-opening-down.stl
Roller-300.stl
design/adversarial-review-2026-10-06/body-1.step
design/adversarial-review-2026-10-06/body-10.stl
design/adversarial-review-2026-10-06/body-11.step
design/adversarial-review-2026-10-06/body-12.step
design/adversarial-review-2026-10-06/body-13.step
design/adversarial-review-2026-10-06/body-13.stl
design/adversarial-review-2026-10-06/body-18.step
design/adversarial-review-2026-10-06/body-19.step
design/adversarial-review-2026-10-06/body-2.step
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

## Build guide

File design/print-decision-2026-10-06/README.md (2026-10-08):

# Fresh print decision, 2026-10-06

**Print the five small interface parts first.** [The corrected receiving-fit project](../../first-prints/receiving-fit-gate-2026-10-06/Roller-300-small-fit-gate.3mf) is approximately25.48g /1h16min in Bambu Studio. The fixture and wheel follow successful hardware/PETG fits. No physical test or print has occurred.

The installed native CAD application freshly replayed the current 2,015-feature archive without feature errors and exported all eleven print bodies. Every fresh native mesh hash matches the current print sources; this review did not rely only on prior validation counts. [Fresh native replay](fresh-native-replay.json).

Independent assembly probes confirm the actual E-clip insertion path clears the bench input module. A0.8x3mm flat pusher clears the module but intersects the installed fixture, so fit/remove the clip before mounting the carrier. The210mm pitch-line belt length agrees with nominal center distance, and the2mm inward carrier travel allows installation slack. Nominal screw-depth clearance is coherent; physical thread and center-screw fit remain open.

Actual G-code exposed issues missed by warning-free slicing: PETG support in the narrow clip pocket, support in long carrier nut-loading channels, and an output-pulley brim approximately0.08mm beyond the bed edge. The old ten-part review project is superseded and should not be printed. The small project blocks support only at the clip cavity/roof. Its cavity has zero support paths; its roof has bridge paths, with the longest individual move9.23mm. Five first layers are connected, structural perimeter paths are at least0.42mm, both pulley lands are deposited, and brims/supports stay over46mm inside the bed. [Small-project toolpaths](small-plate-toolpaths.json).

The original projects also omitted Bambu's changed-setting metadata. The GUI restored its default two walls/grid infill/disabled support despite correct CLI-sliced values. The export builders now preserve process overrides, matching G-code settings and MD5. The repaired small project was reopened in the native GUI, verified at five walls/15% gyroid/normal support, and freshly resliced to the same25.48g /1h16min estimate. Its clip cavity and roof were inspected in the native layer preview at Z8.78 and9.4.

The current geometry remains nominally suitable for an unpowered fit article. The receiving test must establish keyed-bore fit, horn/screw seating, E-clip seating after bridging, support cleanup and actual nut fit. Later carrier/fixture assembly must establish608 seat fit, free rotation, shaft/pulley endplay and belt tracking. The609g wheel remains a later print. Powered loads and the full barrel remain deferred.

The [corrected full plate](../../first-prints/corrected-full-fit-2026-10-06/Roller-300-full-fit-corrected.3mf) passed the final support/settings/mesh inspection: its clip pocket and both long nut channels contain zero support paths, deposited bed margin is 3.92 mm, and first-layer footprints do not overlap. It remains conditional on physical fits. At print Z47.8, its carrier roofs have unsupported wall/overhang runs of 9.12 mm and 16.37 mm rather than explicit Bridge paths. Use [the separate carrier trial](../../first-prints/carrier-roof-trial-2026-10-06/Roller-300-carrier-roof-trial.3mf), approximately 55.05 g /2 h 22 min, to check sag, bearing seats and nut insertion before the larger fixture. [Full-project toolpaths](corrected-full-toolpaths.json). The small project is the recommended first print.

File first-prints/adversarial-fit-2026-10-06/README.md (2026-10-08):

# S20 one-drive unpowered fit prints

This folder predates the S21 chassis access corrections. Its wheel STL and individual wheel estimate are historical: the four hub screw drivers were blocked by the outer wheel plate, and support extraction from the broad closed wheel cavities remains unqualified. Do not print this wheel. A current native wheel export, slice and support-removal review are required after the access corrections.

The ten smaller drivetrain STLs are separate from that wheel correction. The individual estimate projects and original ten-part review plate are superseded as print instructions: actual toolpaths/settings checks found support cleanup and GUI-preset issues. Start with [the corrected five-part fit gate](../receiving-fit-gate-2026-10-06/Roller-300-small-fit-gate.3mf). Then use the corrected carrier trial before larger parts. See [the fresh print decision](../../design/print-decision-2026-10-06/README.md).

Current native exports for PETG /0.4mm X2D:11 connected pieces,0.2mm layers,5 walls,15% gyroid. `source.json` records native-body and archive hashes; `slice-checks.json` records warning-free individual Bambu slices. Placement applies rigid rotation/translation only.

The original ten-part Bambu project is historical and should not be printed. The approximately609g /15.74h wheel figure is a historical estimate of the superseded geometry; it is not a current wheel print instruction.

Parts: roof-open fit section, sliding carrier,48T output pulley, upper servo bridge, positive REX horn adapter,24T keyed pulley, mouth retainer, two input retainers, center retainer and wheel. Do not use old clamp/collar print files or the inspection cutaway. No physical print or test has occurred.

See [PLAN.md](../../PLAN.md) for ordered assembly and [BOM.xlsx](../../BOM.xlsx) for hardware. Physical fits/endplay and powered/full-barrel qualification remain pending.

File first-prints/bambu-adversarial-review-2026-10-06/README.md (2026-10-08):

# S20 Bambu first-fit review

**SUPERSEDED — DO NOT PRINT THIS PROJECT.** Actual toolpath inspection found support inside the clip/nut-loading cavities, an edge brim and missing GUI setting-override metadata. Start with [the corrected five-part gate](../receiving-fit-gate-2026-10-06/Roller-300-small-fit-gate.3mf). See [the fresh print decision](../../design/print-decision-2026-10-06/README.md). The following estimates are historical.

Open `Roller-300-REX-first-fit.3mf` in Bambu Studio. Ten smaller pieces are arranged for X2D /0.4mm /Generic PETG,0.2mm layers,5 walls,15% gyroid. Offline native Bambu slice passes without warnings, approximately295.9g /9.78h. The final project meshes match current native export/print meshes. No print sent.

The wheel is separate in [the eleven-piece print set](../adversarial-fit-2026-10-06/README.md). Check small hardware fits before that609g print. Assembly order and retention are in [PLAN.md](../../PLAN.md).

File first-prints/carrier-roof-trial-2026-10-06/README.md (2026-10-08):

# Carrier roof trial — unpowered

Print this carrier separately after the five-part receiving gate passes. This project contains one unchanged native carrier and two nonprinting support blockers, using X2D / PETG / 0.4 mm / 0.2 mm / 5 walls / 15% gyroid. Estimated material: 55.05 g; time: 2.37 hours.

The purpose is to prove the unsupported bridge-nut channel roofs at print Z47.8 mm. The corrected full plate has unsupported wall runs approximately 9.12 mm on one post and 16.37 mm on the other. Inspect for sag, clean the accessible supports, and verify nuts insert fully and M3 screws pass through without forcing or cracking the posts. A successful slice is not proof of roof quality, dimensional accuracy, or load-bearing capacity.

Unpowered fit only. No print has been submitted.

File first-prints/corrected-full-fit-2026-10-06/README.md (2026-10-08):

# Corrected full fit plate — later stage

Start with [the small receiving-fit plate](../receiving-fit-gate-2026-10-06/Roller-300-small-fit-gate.3mf). Then trial the corrected carrier alone. This full plate follows successful hardware seating, clip seating and carrier roof/nut-capture tests.

[Roller-300-full-fit-corrected.3mf](Roller-300-full-fit-corrected.3mf) contains ten unchanged S20 native print meshes. Nonprinting support blockers keep the E-clip pocket and carrier nut-loading channels clear; the large fixture and output pulley have moved to provide bed margin. X2D /0.4 mm /PETG /0.2 mm layers /five walls /15% gyroid; approximately 294.12 g /9 h 41 min. Its process overrides persist on reopening.

Fresh actual toolpaths have zero support in the queried clip/nut cavities, no first-layer footprint overlaps and a 3.92 mm bed margin. The carrier's pocket roofs include unsupported wall/overhang runs of 9.12 mm and 16.37 mm. They require a physical trial for sag and nut insertion; warning-free slicing does not establish that result. The old individual carrier slice fills those channels and should not be used for this trial.

The five small parts can be reused in the final assembly. Remove their duplicates from this plate and reslice if those first prints fit. The separate 609 g wheel remains deferred until the interfaces and carrier fit. No physical print, powered test or printer submission has occurred.

[Fresh print decision](../../design/print-decision-2026-10-06/README.md), [toolpath inspection](../../design/print-decision-2026-10-06/corrected-full-toolpaths.json), [mesh/settings validation](../../design/print-decision-2026-10-06/print-project-validation.json).

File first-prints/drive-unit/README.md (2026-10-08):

# Historical drive-unit export — superseded, do not print this set

The instructions below describe an obsolete drivetrain and shell/hatch candidate. They do not apply to the current native assembly. The shaft stack, pulley mounting, retainers and clutch architecture have changed; do not order hardware or print a chassis from this folder.

Start with [the current five-piece receiving fit gate](../receiving-fit-gate-2026-10-06/Roller-300-small-fit-gate.3mf), then [the isolated carrier roof trial](../carrier-roof-trial-2026-10-06/Roller-300-carrier-roof-trial.3mf). The full chassis, wheel and curved hatch need their own current fit review before release. See [the current plan](../../PLAN.md).

## Archived instructions

Every file here except the `*-assembly.stl` pair is bed-oriented. Open this folder in the slicer and print the set. This is a fit assembly for one left drive with a belt and bearings. It is not a powered-test release. Bearing seats are the trial diameters already in the model.

| Part | File | Notes |
|---|---|---|
| 24T input pulley | `input-pulley-24t.stl` | 26 × 26 × 14.5 mm. Bore 8.2 mm for the 8 mm input shaft |
| 48T output pulley | `output-pulley-48t.stl` | 49 × 49 × 14.5 mm. Bore 27 mm |
| Shaft sleeve | `output-pulley-shaft-sleeve.stl` | OD 26.6, ID 8.2, length 14.5. Slips the 48T pulley onto the 8 mm wheel shaft |
| Input carriage | `left-input-carriage-floor-down.stl` | Two input 608 seats |
| Input cap, inner | `input-cap-inner-axle-vertical.stl` | |
| Input cap, outer | `input-cap-outer-axle-vertical.stl` | |
| Wheel cap, inner | `wheel-cap-inner-axle-vertical.stl` | |
| Wheel cap, outer | `wheel-cap-outer-axle-vertical.stl` | |
| Wheel | `left-wheel-axle-vertical.stl` | Rigid rim. 246 mm OD includes tread that is not on this mesh |
| Main shell | `main-shell-opening-down.stl` | Wheel-bearing saddles. About 1.10 kg and 30 h with supports |
| Hatch | `curved-hatch-axle-vertical.stl` | About 145 g |

The `*-assembly.stl` files are the pulleys in model coordinates (input center X=49.67, both pulleys Y 75.75–90.25, axle Z=123). Do not slice those. That position centers them between the input posts at Y66–74 and Y92–100, with 1.75 mm of clearance on each side.

The pulleys are the native prototypes from `Roller-300.nbcad` (input body 10, output body 9). The sleeve is there because the 48T bore is 27 mm. It is a slip fit so the belt can be assembled. It is not the clutch.

## Bring to the bench

- Four 608 bearings. Input centers at |Y|=70 and 96. Wheel centers at |Y|=51 and 99.
- One 210-3M-09 belt (3 mm pitch, 9 mm wide, 70 teeth).
- One 8 mm input shaft, 49 mm long (Y 52 to 101).
- One 8 mm wheel shaft, 113 mm long (Y 35 to 148).
- M3 screws for the input caps. M4 screws for the wheel caps and the hatch.
- The goBILDA hub and the inboard collar if the wheel is retained the way the model shows.

Put the belt around the pulleys before the shafts go into the bearings. The servo horn and the clutch are not in this set.

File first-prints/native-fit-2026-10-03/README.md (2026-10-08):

# Unpowered native fit parts — 2026-10-03

Source: `Roller-300.nbcad`, 1,208 native features. PETG, X2D, 0.4 mm nozzle. No physical print has been performed or sent. These files supersede older print candidates.

Start with `outer-wheel-bearing-coupon.stl` and `wheel-bearing-retainer.stl`: approximately **24 g / 58 minutes** when sliced separately. This tests the 22.2 mm trial608 seat,18 mm shoulder clearance, M3 captive nuts and recessed heads before larger prints. Use four M3x16 bolts and M3 nuts; verify engagement and free bearing rotation. This coupon represents the outer bearing mount, not a complete wheel.

Then test `servo-shaft-clamp-trial.stl` and `input-pulley-clamp-trial.stl` on the uncut8 mm shaft, using M3x10 bolts/nuts. The purchased servo horn interface is excluded until its actual mounting pattern, boss and screw engagement are measured.

The one-drive shell section preserves the left servo mount, both input bearings, and center/mouth wheel-shaft supports. Print `one-drive-fit-section.stl` after small fits pass: **231 g / 6.4 hours**. Add the upper bridge and center, mouth and two input bearing retainers. Use nominal608 bearings, uncut150 mm wheel and50 mm input shafts, an8x25x6 metal input stop collar and2 mm of metal inner-race shims. Retainers must seat freely; set measured endplay without bearing preload. `test-record.json` lists trial hardware and observations.

The full left wheel candidate slices at **613 g / 15.9 hours**, including support. Review its print strategy/mass before that expenditure. A complete wheel/tyre is required later to assess stiffness, clearance and loads; small coupons do not establish those results.

All eleven current candidates slice without warnings with installed Bambu Studio X2D/Generic PETG settings:0.2 mm layers, five walls,15% gyroid, supports where enabled. Native CAD STEP/STL connectivity checks pass. Preparation changes only orientation, placement and serialization; the placement3MF shares vertex references. No custom renderer is used. Review toolpaths in `slicer-check/<part>/<part>-estimate.3mf`; estimates are in `slice-estimates.json`, source hash in `source.json`.

Inspect support removal at bores, nut pockets and servo walls, then record received fits. The supplied drawing labels the270-degree variant; the owned360-degree case, ears and cable boot still need physical confirmation. The shaft-driven clutch and its preload remain unresolved for powered operation. This package is for unpowered fit work.

Assembly: load captive nuts while accessible; install bearings against outer-race shoulders; close retainers and confirm free rotation; insert servo with its bridge removed; fit ear/bridge bolts; install shaft clamps, pulleys and belt; set metal stop and measured endplay. Add the measured horn adapter later. Check driver and cable access physically.

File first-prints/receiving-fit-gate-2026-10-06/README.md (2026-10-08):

# Small receiving-fit test

Print [Roller-300-small-fit-gate.3mf](Roller-300-small-fit-gate.3mf) first. It contains the unchanged S20 native horn/REX adapter, input pulley, upper servo bridge, mouth retainer and one input retainer. The added support blocker is a slicer instruction and does not print.

X2D, 0.4 mm, PETG, 0.2 mm layers, five walls and 15% gyroid. Native Bambu CLI and a fresh GUI reslice agree at approximately **25.48 g / 1 h 16 min**. Reopening preserves the intended process overrides. No job was sent to a printer.

The adapter's E-clip pocket is free of support paths. Its roof bridges at Z9.4; the longest individual bridge move is 9.23 mm. Remove accessible supports from the horn recess, pulley bore/flanges and short bridge nut pockets. This is a physical bridge/fit trial; a successful slice does not establish the printed clearance.

Check the actual REX shaft slides through both keyed bores, the supplied clip seats fully without damage, the metal horn pilot and four mounting screws seat, and the actual M3 center screw fits without bottoming. Check actual nuts and screw heads in these representative captures. Check both printed pulley lands are clean and flat against bearing inner races. The carrier's bearing seats and complete shaft endplay require the later carrier/fixture assembly; these five pieces do not establish those fits.

Install the E-clip with the input module on the bench, before mounting the carrier in the fixture. A tested flat pusher clears the bench module but is obstructed by the installed fixture.

After these checks pass, print [the corrected carrier trial](../carrier-roof-trial-2026-10-06/Roller-300-carrier-roof-trial.3mf), approximately 55.05 g /2 h 22 min, for its unsupported pocket roofs, nut loading and bearing seats. Then proceed to the larger fixture/assembly and measure bearing seating, 0.2 mm nominal shaft play, 0.4 mm nominal pulley play and belt tracking. Hold the separate approximately609 g wheel until the interfaces work. Keep the article unpowered.

Fresh evidence: [print decision](../../design/print-decision-2026-10-06/README.md), [native replay](../../design/print-decision-2026-10-06/fresh-native-replay.json), [toolpath inspection](../../design/print-decision-2026-10-06/small-plate-toolpaths.json), [project geometry/settings validation](../../design/print-decision-2026-10-06/print-project-validation.json).

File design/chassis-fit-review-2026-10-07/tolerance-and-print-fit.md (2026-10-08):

# Chassis print fit review

Scope: geometric fit, hardware insertion/retention, driver access and print cleanup for an unpowered PETG article. This is not a load or strength qualification. No physical print or hardware receiving test has been performed.

The fresh S20 native baseline is `Roller-300.nbcad`, SHA256 `bf4561cd9261083763b1f117bf14007dcaf6202b5efd19679aec39a4e36bd52b`, 2015 features. The independent native replay reports zero errors. S21 corrections are recorded separately; the findings below identify what triggered them.

## Confirmed fit findings

- The actual moving wheel-to-mouth-retainer gap is **0.5 mm** on both sides, while the wheel-to-shell end gap is5 mm. At the permitted0.2 mm wheel endplay, the retainer clearance can fall to0.3 mm before printed runout/warp. Native overlap is zero; the PETG wheel must still rotate freely while pushed to both axial stops. See `fresh-native-wheel-clearances.json`.
- Fresh STEP envelopes give rigid wheel diameter230 mm, wheel outer faces atY±150 (300 mm wide), shaft endpointsY±158 (**316 mm metal width**), and tread placeholders diameter246 mm. The tread is a planning envelope. Without that8 mm radial tread, nominal shell belly ground clearance is35 mm, rather than43 mm. No additional wheel end screw is modeled; clamp screw projection is not represented by the generic hub/collar envelopes.
- Four wheel D4.4 bores are correctly centered on a16 mm square and cross the4 mm webY133.5..137.5. However, the old closed outboard plateY142..150 blocked every straight driver. Exact D3.5 cylinder probes intersect76.969 mm³ at each position on both wheels, although nominal D7x4 socket heads themselves fit. See `wheel-driver-probes.json`. S21 must remove the obstruction in native CAD before a new wheel project is used.
- The old closed wheel also enclosed broad D216 support cavities. Historical actual G-code contains approximately105.9 g of supports below the hub web and42.4 g in the4.5 mm shallow cavity above it. Four small screw ports alone do not establish removal of that support. See `wheel-support-cavities.json`. Opening both faces preserves the hub web/rim and provides direct cleanup and driver paths; the fresh candidate still needs a new slice and cleanup inspection.
- The structural hatch141 and electronics envelope bodies15/16/17 are absent from the active native S20 inventory. Historical curved-hatch and complete-shell projects are not a current closed-chassis release. The shell mesh is valid, but a complete closure/retention and electronics package is unqualified.
- Full-shell straight access to the rear carrier screw is obstructed by the upper guard; the roof-open fixture373 avoids the guard. The independent native agent owns the specific corridor correction and its fresh probes.

## Receiving fit gates

Use actual purchased hardware to qualify printed holes; nominal CAD clearance does not establish a PETG fit. Do not apply a universal hole compensation based only on a successful slice.

1. Print the25.48 g /1 h16 min five-piece receiving gate. Check the actual metal horn pilot and four M4x6 screws, REX AF7.3 bores, factory clip seating/removal through its slot, the bridge face-loaded nuts, and retainer passages. The clip roof bridge and receiving fits are physical test targets.
2. Print the55.05 g /2 h22 min isolated carrier trial. Check actual608 bearings in the22.2 mm seats, their full seating/removal and free rotation, actual M3 nuts in AF6/depth2.8 captures, M4 nuts in their captures, and both unsupported nut-channel roofs. The two longest unsupported roof wall runs are9.12/16.37 mm; slicer bridge labels alone do not qualify their quality.
3. Test the roof-open fixture before the whole shell. Load the three carrier nuts from their intended ports, fit washers and screws, exercise the complete adjustment range, then assemble the shaft/hub/spacer stack and set measured endplay without loading bearing outer races. Verify all drivers with real tools.
4. Use a fresh open-face wheel candidate only after those fits. Check the D14.4 pilot against the actual D14 metal hub, D4.4 bores with four actual M4x10 screws, head and driver insertion, nominal6 mm thread engagement without bottoming, and actual clamp screw access. Bench-assemble the wheel/hub first. The purchased Hyper Hub and collar clamp screw geometry remains unmodeled; no virtual clamp-access pass is claimed.
5. Check full chassis running clearance with the wheel installed at both axial stops, across a complete revolution. Measure wheel face runout near the retainer and remove only residual support material. If the actual gap closes, correct the CAD clearance/stack before a second expensive print.

If a carrier seat fails, use a short native CAD coupon in the same print orientation and local wall construction before changing the whole assembly. A candidate22.1/22.2/22.3/22.4 mm bearing-seat ladder brackets the current22.2 mm starting value. Actual nuts and shafts should be tried in the unchanged receiving parts first; a cosmetic or unrelated coupon does not qualify their narrow roofs/capture entrances.

Current source inconsistencies identified for register correction: `parameters.wheel_collars` retains the oldY35.5..44.5 collar/10 mm spacer language; the current assembly isY85.8..94.8 plus3 mm inboard and6+2 mm outboard spacers. BOM H08 provisionally counts four M3x12 servo-ear screws, while the active servo/PLAN describes M3x10. The extra2 mm tip travel requires clearance verification; correct engagement alone is insufficient. Wheel screws H04 and carrier washers H19 remain exact-candidate/source receiving gates.

Historical `first-prints/drive-unit/README.md` has been explicitly superseded. All closed-face606/609 g wheel projects are historical; they must not be treated as the new open-face wheel slice.

## Validated S21 fit candidate

The native candidate `.local/s21-chassis-access-replayed.nbcad` has2033 features, zero replay errors, source SHA256 `f44c1acb824ed2a0a4b773db5265e754d7f9c1fd45e0c9c5e64d964533201312`. It removes both wheel closure faces insideR108, preserving the4 mm mounting web and7 mm radial rim, and adds the rear carrier driver passages. Native exact probes report valid one-solid wheels, unobstructed head/driver/shank paths, and wheel-to-retainer clearance24 mm (23.8 mm at inward0.2 mm play); the former0.5 mm clearance finding is resolved by the open-face correction.

The selected held wheel project is [the outboard-face-down candidate](../../first-prints/chassis-fit-2026-10-07/outboard-down/Roller-300-wheel-open-fit.3mf): **336.71 g /8 h38 min**, X2D main nozzle, PETG,0.4 mm,0.2 mm,5 walls,15% gyroid and normal auto supports. Its4064 triangles preserve the native STL connectivity and vertices within0.0000043 mm after rigid placement. The actual G-code has one connected annular first layer, minimum10.137 mm bed margin, support atZ0.2..12.4 only, and zero support in the mounting/pilot bores or above the retained web. Outer/inner wall widths are at least0.42 mm; sub0.2 mm paths are gap fill, not structural walls.

Approximately87.38 g of support remains beneath the web, directly accessible through theD216 bed-facing opening. Physical support removal and actual hardware/PETG fits remain tests. The alternative inboard-down candidate is preserved for inspection at398.76 g /9 h52 min; flipping the unchanged wheel saves62.05 g and1 h13 min. Do not print both candidates.

Evidence: `s21-wheel-outboard-toolpaths.json`, `s21-access/exact-fit-inspection.json` and the selected project's `wheel-slice-check.json`. Canonical native save/provenance reconciliation is owned by the root review; no wheel print or whole-chassis release is implied by this candidate slice.

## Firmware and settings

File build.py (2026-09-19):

"""Rebuild the Roller-300 packaging study from parameters.json using installed NoBS CAD.
Creates an isolated headless CAD process. Never attaches to or clears a desktop document.
All geometry is packaging/source evidence, NOT production or physical validation.
Run with the bundled Python runtime. --draw-only refreshes the current component sheet.
--refresh reuses unchanged independent bodies from the last native export.
"""
from pathlib import Path
import json, math, subprocess, sys, zipfile, datetime, base64
from PIL import Image, ImageDraw, ImageFont
from array import array
ROOT=Path(__file__).resolve().parent
P=json.loads((ROOT/'parameters.json').read_text())
R=P['wheel_diameter']/2; BR=P['body_diameter']/2
# Stored component positions use the axle frame; world Z is derived once.
for key in ['battery','pixracer','pi']:
 P[key+'_min_xyz']=[v+(R if j==2 else 0) for j,v in enumerate(P[key+'_min_xyz_axle'])]
P['servo_z0']=R+P['servo_z_from_axle']
for q in P['mass_estimates']:
 q['xyz']=[v+(R if j==2 else 0) for j,v in enumerate(q['xyz_axle'])]
P.update(body_length=2*BR,body_rear_x=-BR,body_floor_z=R-BR,body_height=2*BR)
GA=P['gear_module']*sum(P['gear_teeth'])/2
GI=P['gear_teeth'][1]/P['gear_teeth'][0]
bt=P['belt_trial']; BPR=[t*bt['pitch_mm']/(2*math.pi) for t in bt['pulley_teeth']]
def belt_length(c):
 r1,r2=BPR
 return 2*math.sqrt(c*c-(r2-r1)**2)+math.pi*(r1+r2)+2*(r2-r1)*math.asin((r2-r1)/c)
lo,hi=BPR[1]-BPR[0]+.01,bt['pitch_length_mm']/2
for _ in range(60):
 mid=(lo+hi)/2
 if belt_length(mid)>bt['pitch_length_mm']:hi=mid
 else:lo=mid
A=(lo+hi)/2; I=bt['pulley_teeth'][1]/bt['pulley_teeth'][0]
GEAR_RO=[P['gear_module']*(t+2)/2 for t in P['gear_teeth']]
TRACK=P['body_width']+2*P['wheel_gap']+P['tire_width']
HW=P['body_width']/2; TY=HW+P['wheel_gap']; SW=P.get('bearing_support_width',46)
parts=[]
COL={'printed':(92,141,151),'purchased':(123,133,149),'unresolved':(214,149,67),'tire':(61,67,76),'clearance':(115,174,125),'conflict':(190,75,70)}
COL.update(optics=(176,106,162),range_sensor=(69,161,147),belt=(61,67,76))
def box(name,lo,sz,kind='printed',holes=None):
 parts.append(dict(name=name,type='box',lo=lo,sz=sz,kind=kind,holes=holes or []));return parts[-1]
def ring(name,x,z,y0,length,ro,ri=0,kind='purchased',trim=None):
 parts.append(dict(name=name,type='ring',x=x,z=z,y0=y0,length=length,ro=ro,ri=ri,kind=kind,trim=trim));return parts[-1]
shell=ring('P barrel lower shell; integration study',0,R,-HW+3,2*HW-6,BR,BR-P['skin'],'printed',('above',R+P['body_lid_split_height_above_axle']))
lid=ring('P removable curved electronics lid',0,R,-HW+3,2*HW-6,BR,BR-P['skin'],'printed',('below',R+P['body_lid_split_height_above_axle']))
# Camera openings await actual lens centers and complete connector envelopes.
nr=BR
for s,side in [(1,'L'),(-1,'R')]:
 def yr(a,b): return (a,b-a) if s==1 else (-b,b-a)
 def sr(n,x,z,a,b,ro,ri=0,k='purchased'):
  y,l=yr(a,b);return ring(f'{side} {n}',x,z,y,l,ro,ri,k)
 def sb(n,x,z,a,b,dx,dz,k='printed',holes=None):
  y,l=yr(a,b);return box(f'{side} {n}',[x,y,z],[dx,l,dz],k,holes)
 cv=sr('P transmission cover allowance',0,R,HW-3,HW,BR,8.5,'printed');cv['holes']=[(A,R,8.5)]
 sr('P wheel rim allowance; replace with ribs',0,R,TY,TY+P['tire_width'],R-P['wheel_tread_radial'],25,'printed')
 sr('P TPU tire allowance',0,R,TY,TY+P['tire_width'],R,R-P['wheel_tread_radial'],'tire')
 sr('B 8 mm smooth wheel shaft',0,R,*P['wheel_shaft_y'],4)
 sr('B 8 mm smooth input shaft',A,R,*P['input_shaft_y'],4)
 for x,ys,tag in [(0,P['output_bearing_y'],'wheel'),(A,P['input_bearing_y'],'input')]:
  for j,yc in enumerate(ys):
   sr(f'B 608 {tag} bearing {j+1}',x,R,yc-3.5,yc+3.5,11,4)
   low=R-math.sqrt((BR-4)**2-min(abs(x)+SW/2,BR-5)**2)
   # Lower saddle and removable cap have independently cut bearing-seat openings.
   sb(f'P integrated {tag} saddle {j+1}',x-SW/2,low,yc-4.5,yc+4.5,SW,R-low,
      holes=[(x,R,(P['bearing_od']+P['bearing_seat_diametral_allowance'])/2)])
   sb(f'P removable {tag} bearing cap {j+1}',x-SW/2,R,yc-4.5,yc+4.5,SW,17,
      holes=[(x,R,(P['bearing_od']+P['bearing_seat_diametral_allowance'])/2)])
 # Published clutch envelope; plate/bush detail is an explicitly unresolved interface.
 cy=P['clutch_y0']; ce=cy+P['clutch_length']; boss=ce-P['clutch_boss_length']
 sr('U ComInTec 00.25 DF d8 T1 supplier envelope; qualification pending',0,R,cy,ce,P['clutch_od']/2,4,'unresolved')
 sr('U proposed ground metal drive plate OD40 x2; bore/bush unresolved',0,R,82,84,20,0,'unresolved')
 fy=bt['pulley_face_y0_mm'];fw=bt['pulley_axial_envelope_mm']
 sr('U 48T pulley PITCH envelope; metal plate adapter unresolved',0,R,fy,fy+fw,BPR[1],13.5,'unresolved')
 sr('U 24T pulley PITCH envelope; no tooth form',A,R,fy,fy+fw,BPR[0],4,'unresolved')
 theta=math.acos((BPR[1]-BPR[0])/A)
 def belt_contour(offset):
  r1,r2=[v+offset for v in BPR]
  return [[r2*math.cos(a),R+r2*math.sin(a)] for a in [theta+(2*math.pi-2*theta)*j/20 for j in range(21)]]+[[A+r1*math.cos(a),R+r1*math.sin(a)] for a in [-theta+2*theta*j/16 for j in range(17)]]
 y,length=yr(fy+1.5,fy+1.5+9)
 parts.append(dict(name=f'{side} B 210-3M-09 belt LOOP ENVELOPE',type='poly',y0=y,length=length,contours=[belt_contour(1.5),belt_contour(-1.5)],kind='belt'))
 for location in ['inboard','outboard']:
  sr('B 2910-0921-0008 wheel collar '+location,0,R,*P['wheel_collars'][location+'_y'],10.5,4)
 sr('B 1310-0016-0008 wheel hub full circumscribed envelope',0,R,*P['wheel_hub']['overall_y'],15.3,4)
 sr('P wheel mounting web allowance; M4 pattern16 square',0,R,116,120,25,7,'printed')
 sv=P['servo_reserve_xyz'];sx=A+P['servo_x_offset_from_axis']
 sb('B goBILDA25-2 full fixed hardware envelope from STEP',sx,P['servo_z0'],P['servo_min_abs_y'],P['servo_min_abs_y']+sv[1],sv[0],sv[2],'purchased')
 # Horn and misalignment-tolerant torque-only bridge; NOT a torque limiter.
 sr('U included matching horn sweep; sample measurement pending',A,R,54.1,61,12,3,'unresolved')
 sr('P floating horn drive bridge allowance',A,R,61,68,10,4,'printed')
 sb('P servo cradle landing; replaceable retainer to detail',sx,P['servo_z0']-4,P['servo_min_abs_y'],54.1,sv[0],4)
 # Removable axial retention is kept separate from clutch preload.
 sr('U input retention allowance - actual hardware NOT selected',A,R,63,69,7,4,'unresolved')
for name,key in [('Battery','battery'),('Pixracer','pixracer')]:
 box('U '+name+' installation reserve',P[key+'_min_xyz'],P[key+'_size_xyz'],'unresolved')
box('B Pi Zero Wi-Fi nominal bare-board envelope - variant pending',P['pi_min_xyz'],P['pi_size_xyz'],'purchased')
b=P['battery_min_xyz'];bs=P['battery_size_xyz']
box('P battery cradle floor',[b[0]-2,b[1]-2,b[2]-4],[bs[0]+4,bs[1]+4,4])
for x in [b[0]-4,b[0]+bs[0]]:
 box('P battery end stop',[x,b[1]-2,b[2]],[4,bs[1]+4,10])
for key,name in [('pixracer','P controller shelf'),('pi','P removable future Pi shelf')]:
 lo=P[key+'_min_xyz'];sz=P[key+'_size_xyz']
 box(name,[lo[0]-2,lo[1]-2,lo[2]-4],[sz[0]+4,sz[1]+4,4])
# Wire volumes are empty keep-outs, not solid printed ducts or selected cables.
for q in P['harness_reserves']:
 lo=[v+(R if j==2 else 0) for j,v in enumerate(q['min_xyz_axle'])]
 box('C '+q['name']+' - EMPTY HARNESS SPACE',lo,q['size_xyz'],'clearance')
q=P['power_distribution_reserve']
box('U power distribution / cutoff reserve',[v+(R if j==2 else 0) for j,v in enumerate(q['min_xyz_axle'])],q['size_xyz'],'unresolved')
th=P['camera_layout']['thermal']
box('B TOPDON TC002C Duo overall incl built-in USB plug',[v+(R if j==2 else 0) for j,v in enumerate(th['trial_min_xyz_axle'])],th['trial_size_xyz'],'optics')
# ToF has an exact front footprint but unknown depth; visible camera identity is unknown.
# Neither is represented by a guessed solid. Footprints and intended zones appear in sections.


def calculations():
 def intersects(a,b):
  return all(min(a['lo'][j]+a['sz'][j],b['lo'][j]+b['sz'][j])-max(a['lo'][j],b['lo'][j])>1e-6 for j in range(3))
 hardware=[q for q in parts if q['type']=='box' and q['kind'] in ['purchased','unresolved','optics']]
 wires=[q for q in parts if q['kind']=='clearance']
 structure=[q for q in parts if q['type']=='box' and q['kind']=='printed']
 thermal=next(q for q in hardware if 'TOPDON' in q['name'])
 rmax=max(math.hypot(thermal['lo'][0]+i*thermal['sz'][0],thermal['lo'][2]+j*thermal['sz'][2]-R) for i in [0,1] for j in [0,1])
 data={'revision':P['revision'],'scope':'Current mechanical CAD packaging checks only. No physical tests or complete-installed-fit claim.',
  'width_mm':TRACK+P['tire_width'],'wheel_diameter_mm':2*R,'body_diameter_mm':2*BR,'body_width_mm':2*HW,
  'active_belt_centers_mm':A,'belt_ratio':I,'nominal_shell_ground_clearance_mm':R-BR,
  'hardware_box_intersections':[[a['name'],b['name']] for k,a in enumerate(hardware) for b in hardware[k+1:] if intersects(a,b)],
  'harness_box_intersections':[[a['name'],b['name']] for a in wires for b in hardware+structure if intersects(a,b)],
  'thermal_inner_shell_corner_clearance_mm':BR-P['skin']-rmax,
  'thermal_above_servo_reserve_gap_mm':thermal['lo'][2]-(P['servo_z0']+P['servo_reserve_xyz'][2]),
  'pi_nominal_hardware_xyz_mm':P['pi_size_xyz'],'thermal_nominal_hardware_xyz_mm':thermal['sz'],
  'range_module_front_outline_width_height_mm':[20,12],'range_module_depth_mm':None,'visible_camera_size_mm':None,
  'optical_apertures_and_mated_connectors_complete':False,'raised_cover_withdrawn':True,
  'clutch_outer_bearing_nominal_gap_mm':(P['output_bearing_y'][1]-P['bearing_width']/2)-(P['clutch_y0']+P['clutch_length']),
  'clutch_inner_bearing_nominal_gap_mm':P['clutch_y0']-(P['output_bearing_y'][0]+P['bearing_width']/2),
  'wheel_bearing_span_mm':P['output_bearing_y'][1]-P['output_bearing_y'][0],
  'drive_detail_open':['input shaft retention and torque-only horn bridge','pulley tooth form / flanges / tension travel','metal clutch plate bush bore and attachment','wheel web/hub positive joint','cap bolts and axial shoulders'],
  'component_envelopes':P['component_envelopes'],'physical_validation':False,'all_hardware_packaged':False}
 assert abs(data['width_mm']-300)<1e-6
 assert not data['hardware_box_intersections'],data['hardware_box_intersections']
 assert not data['harness_box_intersections'],data['harness_box_intersections']
 assert data['thermal_inner_shell_corner_clearance_mm']>0
 (ROOT/'checks.json').write_text(json.dumps(data,indent=2)+'\n')
 return data

class CAD:
 def __init__(self):
  self.proc=subprocess.Popen([r'C:\Users\jeffg\AppData\Local\nbcad\mcp\nbcad-mcp.exe'],stdin=subprocess.PIPE,stdout=subprocess.PIPE,stderr=(ROOT/'cad-runtime.log').open('w'),text=True,encoding='utf-8',creationflags=0x08000000)
  self.seq=0;self.ids=[];self.trace=[]
 def call(self,n,a=None):
  self.seq+=1;a=a or {};self.proc.stdin.write(json.dumps({'jsonrpc':'2.0','id':self.seq,'method':'tools/call','params':{'name':n,'arguments':a}})+'\n');self.proc.stdin.flush()
  while True:
   line=self.proc.stdout.readline()
   if not line:raise RuntimeError('CAD process ended')
   r=json.loads(line)
   if r.get('id')!=self.seq:continue
   if 'error' in r:raise RuntimeError(r)
   v=r['result']
   if v.get('isError'):raise RuntimeError(n+': '+str(v))
   d=v.get('structuredContent') or json.loads(v['content'][0]['text'])
   self.trace.append({'name':n,'arguments':a});return d
 def sketch(self,plane='xz'):
  name=self.call('sketch_begin',{'plane':{'type':'origin_plane','plane':plane}})['name']
  # Raw-coordinate tools still grid-snap on this installed CAD version.
  self.call('sketch_set_grid_snap',{'enabled':False})
  return name
 def rectangle(self,x,z,dx,dz):self.call('sketch_add_rectangle',{'mode':'two_point','p1':{'x':x,'y':z},'p2':{'x':x+dx,'y':z+dz},'ctrl_held':True})
 def circle(self,x,z,r):self.call('sketch_add_circle',{'mode':'center_diameter','p1':{'x':x,'y':z},'p2':{'x':x+r,'y':z},'ctrl_held':True})
 def extrude(self,sk,l,target=None,through=False,flip=True):
  self.call('sketch_finish')
  d=self.call('solid_extrude',{'sketch_name':sk,'profile_indices':[0],'operation':'cut' if target else 'new_body','extent':{'type':'through_all'} if through else {'type':'distance','distance':l},'taper_angle_deg':0,'flip':flip,'target_body_ids':[target] if target else []})
  if target:return target
  # Returned engine IDs, never guessed from operation count.
  scene=d.get('scene') or self.call('solid_scene');bs=scene.get('bodies',[])
  ids=[b.get('id',b.get('body_id')) for b in bs]
  fresh=[v for v in ids if v not in self.ids]
  if len(fresh)!=1:raise RuntimeError('Expected one new body: '+str(scene.keys())+str(fresh))
  self.ids=ids;return fresh[0]
 def part(self,q):
  sk=self.sketch()
  if q['type']=='box':
   x,y,z=q['lo'];dx,l,dz=q['sz'];self.rectangle(x,z,dx,dz)
  elif q['type']=='poly':
   y=q['y0'];l=q['length']
   for contour in q['contours']:
    for a,b in zip(contour,contour[1:]+contour[:1]):
     self.call('sketch_add_line',{'from':dict(zip(['x','y'],a)),'to_raw':dict(zip(['x','y'],b)),'ctrl_held':True})
  else:
   y=q['y0'];l=q['length'];self.circle(q['x'],q['z'],q['ro'])
   if q['ri']:self.circle(q['x'],q['z'],q['ri'])
  bid=self.extrude(sk,l)
  if y:self.call('solid_move_copy',{'body_ids':[bid],'translation':{'x':0,'y':y,'z':0},'pivot':{'x':0,'y':0,'z':0},'copy':False})
  for x,z,r in q.get('holes',[]):
   sk=self.sketch();self.circle(x,z,r);self.extrude(sk,0,bid,True)
  if q.get('trim'):
   direction,level=q['trim'];sk=self.sketch();self.rectangle(-BR-1,level if direction=='above' else -1,2*BR+2,2*BR+R if direction=='above' else level+1);self.extrude(sk,0,bid,True)
  for x,z,dx,dz in q.get('clip_rects',[]):
   sk=self.sketch();self.rectangle(x,z,dx,dz);self.extrude(sk,0,bid,True)
  for lo,sz in q.get('window_cuts',[]):
   x,yc,z=lo;dx,dy,dz=sz
   self.call('solid_move_copy',{'body_ids':[bid],'translation':{'x':0,'y':-yc,'z':0},'pivot':{'x':0,'y':0,'z':0},'copy':False})
   sk=self.sketch();self.rectangle(x,z,dx,dz);self.extrude(sk,dy,bid)
   self.call('solid_move_copy',{'body_ids':[bid],'translation':{'x':0,'y':yc,'z':0},'pivot':{'x':0,'y':0,'z':0},'copy':False})
  color=COL[q['kind']]
  self.call('set_body_appearance',{'body_id':bid,'material_name':q['name'],'filament_type':'PETG' if q['kind']=='printed' else 'TPU' if q['kind']=='tire' else 'REFERENCE','color_name':q['kind'],'color':dict(zip(['r','g','b','a'],[*color,255]))})
  q['body_id']=bid
 def save(self):
  d=self.call('cad_project_model')
  # Model response is a tagged wrapper on some installed versions.
  if 'value' in d:model=json.loads(d['value']) if isinstance(d['value'],str) else d['value']
  elif 'model_json' in d:model=json.loads(d['model_json']) if isinstance(d['model_json'],str) else d['model_json']
  else:model=d
  if model.get('format')!='nbcad-project':raise RuntimeError('Unexpected project response: '+str(d.keys()))
  names={a['body_id']:a['material_name'] for a in model['body_appearances']}
  cs=model['assembly']['component_structure'];cn={}
  for co in cs['definitions']:
   if len(co['body_ids'])==1:co['name']=str(co['id'])+': '+names.get(co['body_ids'][0],co['name'])
   cn[co['id']]=co['name']
  for oc in cs['occurrences']:oc['name']=cn[oc['component_id']]
  manifest={'format':'nbcad-project','container_version':1,'model':'model.json','model_schema_version':model['schema_version'],'application':'noBS CAD','application_version':'0.1.0','saved_at':datetime.datetime.now(datetime.timezone.utc).isoformat()}
  with zipfile.ZipFile(ROOT/'Roller-300.nbcad','w',zipfile.ZIP_DEFLATED) as z:
   z.writestr('manifest.json',json.dumps(manifest));z.writestr('model.json',json.dumps(model))
  pre=self.call('solid_export_preflight');(ROOT/'cad-check.json').write_text(json.dumps(pre,indent=2))
  scene=self.call('solid_scene');preview(scene,parts)
  (ROOT/'source-map.json').write_text(json.dumps(parts,indent=2))
  exp=self.call('solid_export_step')
  for key,v in exp.items():
   if 'base64' in key and isinstance(v,str):(ROOT/'Roller-300.step').write_bytes(base64.b64decode(v))
  # Native reload is the meaningful editable-file check.
  self.call('cad_load_project_model',{'model_json':json.dumps(model)})
  verify=self.call('solid_export_preflight');(ROOT/'cad-reload-check.json').write_text(json.dumps(verify,indent=2))
  self.proc.terminate()

def preview(scene,source):
 # Orthographic triangle rendering of actual OCCT tessellation, not an imagined product image.
 im=Image.new('RGB',(1800,1000),'white');dr=ImageDraw.Draw(im)
 font=lambda n:ImageFont.truetype('C:/Windows/Fonts/arial.ttf',n)
 dr.text((45,28),'ROUND TWO-WHEEL ROLLER / 300 mm wide',font=font(34),fill=(32,43,54))
 dr.text((45,80),'Native CAD study - selected servo / hubs; amber = unresolved interfaces. Green = wiring space. NOT FOR PRINT.',font=font(23),fill=(158,96,20))
 labels={q['body_id']:q for q in source if 'body_id' in q}
 # Direction to viewer (0.55,0.8,0.4); view X basis perpendicular in XY.
 right=(.824,-.566,0);up=(-.212,-.309,.927);front=(.524,.763,.375)
 for panel in [0,1]:
  triangles=[];cx=470+850*panel;cy=585;scale=1.62
  depth_buffer=array('f',[-1e20])*(1800*1000)
  for body in scene['bodies']:
   q=labels[body['id']];n=q['name']
   if panel and ('lid' in n or 'cover' in n or ('L ' in n and ('wheel rim' in n or 'TPU tire' in n))):continue
   mesh=body['mesh'];v=mesh['positions'];inds=mesh['indices'];normals=mesh['normals']
   color=COL[q['kind']]
   for k in range(0,len(inds),3):
    ids=inds[k:k+3];points=[];depth=0;nn=[0,0,0]
    for idx in ids:
     p=(v[3*idx],v[3*idx+1],v[3*idx+2]-R)
     points.append((cx+scale*sum(p[j]*right[j] for j in range(3)),cy-scale*sum(p[j]*up[j] for j in range(3)),sum(p[j]*front[j] for j in range(3))))
     depth+=sum(p[j]*front[j] for j in range(3))/3
     for j in range(3):nn[j]+=normals[3*idx+j]/3
    brightness=.65+.35*abs(sum(nn[j]*front[j] for j in range(3)))
    triangles.append((depth,points,tuple(int(c*brightness) for c in color)))
  pix=im.load()
  for _,poly,color in triangles:
   for row in range(max(130,math.ceil(min(t[1] for t in poly))),min(840,math.floor(max(t[1] for t in poly)))+1):
    intersections=[];scan=row+.5
    for j in range(3):
     v0,v1=poly[j],poly[(j+1)%3]
     if min(v0[1],v1[1])<=scan<max(v0[1],v1[1]):
      t=(scan-v0[1])/(v1[1]-v0[1]);intersections.append((v0[0]+t*(v1[0]-v0[0]),v0[2]+t*(v1[2]-v0[2])))
    if len(intersections)!=2:continue
    (xl,zl),(xr,zr)=sorted(intersections)
    if xr-xl<1e-9:continue
    dz=(zr-zl)/(xr-xl)
    for col in range(max(0,math.ceil(xl-.5)),min(1799,math.floor(xr-.5))+1):
     zz=zl+(col+.5-xl)*dz;ix=row*1800+col
     if zz>depth_buffer[ix]:depth_buffer[ix]=zz;pix[col,row]=color
  dr.text((55+850*panel,855),'Full exterior envelope' if panel==0 else 'Cutaway: left tire/rim, lids and covers hidden',font=font(25),fill=(32,43,54))
 dr.text((45,915),f'{2*R:g} mm wheels / D{2*BR:g} drum. Thermal + Pi nominal hardware; amber = unselected reserves. Sensor solids incomplete.',font=font(23),fill=(45,55,65))
 im.save(ROOT/'packaging-preview.png')
 bounds=[[min(b['mesh']['positions'][j::3]) for j in range(3)] for b in scene['bodies']]
 upper=[[max(b['mesh']['positions'][j::3]) for j in range(3)] for b in scene['bodies']]
 discrepancies=[]
 for body,low,high in zip(scene['bodies'],bounds,upper):
  q=labels[body['id']]
  if q['type']=='box':
   err=max(abs(low[j]-q['lo'][j]) for j in range(3))
   err=max(err,max(abs(high[j]-q['lo'][j]-q['sz'][j]) for j in range(3)))
   if err>.02:discrepancies.append({'name':q['name'],'max_error_mm':err})
 (ROOT/'native-parameter-check.json').write_text(json.dumps({'scope':'Every rectangular body mesh bounding box versus source, tolerance 0.02 mm. Does not qualify fits or known clutch interference.','box_mismatches':discrepancies},indent=2))
 assert not discrepancies,discrepancies
 (ROOT/'native-bounds.json').write_text(json.dumps({'status':'Tessellated CAD sample bounds; exact circles may extend beyond sampled vertices. No physical validation.','minimum_xyz_mm':[min(b[j] for b in bounds) for j in range(3)],'maximum_xyz_mm':[max(b[j] for b in upper) for j in range(3)],'body_count':len(scene['bodies']),'cad_scene_errors':scene.get('errors',[])},indent=2))
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

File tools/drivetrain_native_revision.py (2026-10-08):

"""Author native CAD feature DTOs. The CAD application must replay every candidate.

This does not generate geometry or render images. Source archives are untouched.
"""
from pathlib import Path
import base64
import copy
import json
import math
import sys
import zipfile

ROOT = Path(__file__).resolve().parents[1]


class Native:
    def __init__(self, source=ROOT / 'Roller-300.nbcad'):
        with zipfile.ZipFile(source) as archive:
            self.entries = {n: archive.read(n) for n in archive.namelist()}
        self.m = json.loads(self.entries['model.json'])
        if len(self.m['document']['history']['features']) != 1208:
            raise ValueError('This one-time migration requires the 1208-feature base. Pass the preserved base archive explicitly; do not reapply it to the revised master.')
        self.fid = max(f['id'] for f in self.m['document']['history']['features'])
        self.did = max(p['datum_id'] for p in self.m['datum_planes'])
        self.bid = max([b for e in self.m['extrudes'] for b in e['new_body_ids']] +
                       [b for e in self.m['body_features'] for b in e.get('result_body_ids', [])])
        self.parts = {}

    def feature(self, kind, name):
        self.fid += 1
        self.m['document']['history']['features'].append(
            dict(id=self.fid, name=name, kind=kind, suppressed=False, status={'state': 'ok'}))
        return self.fid

    def suppress(self, ids):
        for f in self.m['document']['history']['features']:
            if f['id'] in ids:
                f['suppressed'] = True

    def plane(self, axis, pos, name):
        bases = {
            'xz': dict(origin=[0, pos, 0], u=[1, 0, 0], v=[0, 0, 1], normal=[0, -1, 0]),
            'xy': dict(origin=[0, 0, pos], u=[1, 0, 0], v=[0, 1, 0], normal=[0, 0, 1]),
            'yz': dict(origin=[pos, 0, 0], u=[0, 1, 0], v=[0, 0, 1], normal=[1, 0, 0]),
        }
        self.did += 1
        p = dict(feature_id=self.feature('construction_plane', name + ' datum'),
                 name=name + ' datum', datum_id=self.did,
                 source={'type': 'offset', 'reference': {'type': 'origin_plane', 'plane': axis},
                         'distance': -pos if axis == 'xz' else pos}, basis=bases[axis])
        self.m['datum_planes'].append(p)
        self.m['visibility']['hidden_datum_plane_ids'].append(self.did)
        return p

    def extrude(self, name, axis, pos, entities, depth, op='new_body', target=None):
        p = self.plane(axis, pos, name)
        s = copy.deepcopy(next(s for s in self.m['sketches'] if s['feature_id'] == 539))
        s.update(feature_id=self.feature('sketch', name), name=name,
                 plane={'type': 'datum_plane', 'datum_id': p['datum_id']}, basis=copy.deepcopy(p['basis']))
        s['snapshot'].update(entities=entities, constraints=[], next_entity=len(entities) + 1, next_constraint=1)
        self.m['sketches'].append(s)
        self.m['visibility']['hidden_sketch_names'].append(name)
        self.m['counters']['sketch'] += 1
        e = copy.deepcopy(next(e for e in self.m['extrudes'] if e['feature_id'] == 543))
        self.m['counters']['extrude'] += 1
        e.update(feature_id=self.feature('extrude', name), name=name, sketch_name=name,
                 operation=op, extent={'type': 'distance', 'distance': depth}, flip=axis == 'xz',
                 target_body_ids=[] if op == 'new_body' else [target], new_body_ids=[])
        if op == 'new_body':
            self.bid += 1
            e['new_body_ids'] = [self.bid]
        self.m['extrudes'].append(e)
        return self.bid if op == 'new_body' else target

    @staticmethod
    def poly(points):
        n = len(points)
        return [[i + 1, {'type': 'point', 'position': dict(x=x, y=y)}] for i, (x, y) in enumerate(points)] + \
               [[n + i + 1, {'type': 'line', 'start': i + 1, 'end': (i + 1) % n + 1}] for i in range(n)]

    @staticmethod
    def circles(x, y, radii):
        return [[i + 1, {'type': 'circle', 'center': dict(x=x, y=y), 'radius': r}]
                for i, r in enumerate(radii)]

    def box(self, name, lo, size, op='new_body', target=None):
        x, y, z = lo
        dx, dy, dz = size
        return self.extrude(name, 'xz', y, self.poly([(x, z), (x + dx, z), (x + dx, z + dz), (x, z + dz)]), dy, op, target)

    def ring(self, name, y, length, ro, ri, op='new_body', target=None, x=0, z=123):
        return self.extrude(name, 'xz', y, self.circles(x, z, [ro, ri] if ri else [ro]), length, op, target)

    def move(self, bodies, name, x=0, y=0, z=0, copy_bodies=False):
        result = bodies
        if copy_bodies:
            result = list(range(self.bid + 1, self.bid + 1 + len(bodies)))
            self.bid += len(bodies)
        self.m['body_features'].append(dict(type='move_copy', feature_id=self.feature('move_copy', name),
            name=name, body_ids=bodies, translation=dict(x=x, y=y, z=z), rotation=[0, 0, 0, 1],
            pivot=dict(x=0, y=0, z=123), copy=copy_bodies, result_body_ids=result))
        return result

    def mirror(self, bodies, name):
        result = list(range(self.bid + 1, self.bid + 1 + len(bodies)))
        self.bid += len(bodies)
        self.m['body_features'].append(dict(type='mirror', feature_id=self.feature('mirror', name), name=name,
            body_ids=bodies, plane={'type': 'origin_plane', 'plane': 'xz'},
            plane_basis=dict(origin=[0, 0, 0], u=[1, 0, 0], v=[0, 0, 1], normal=[0, -1, 0]), new_body_ids=result))
        return result

    def combine(self, target, tools, op='join', keep=False, name='S13 native combine'):
        self.m['body_features'].append(dict(type='combine', feature_id=self.feature('combine', name), name=name,
            target_body_id=target, tool_body_ids=tools, operation=op, keep_tools=keep))

    def import_step(self, path, name, translation, rotation):
        self.bid += 1
        b = self.bid
        self.m['body_features'].append(dict(type='import_step', feature_id=self.feature('import_step', name),
            name=name, file_name=Path(path).name, data_base64=base64.b64encode(Path(path).read_bytes()).decode(), body_id=b))
        self.move([b], name + ' placement')
        self.m['body_features'][-1].update(translation=dict(zip(('x', 'y', 'z'), translation)), rotation=rotation,
                                          pivot=dict(x=0, y=0, z=0))
        return b

    def drill(self, name, target, y, depth, points, radius):
        entities = [[i+1, {'type':'circle', 'center':dict(x=x,y=z), 'radius':radius}]
                    for i,(x,z) in enumerate(points)]
        self.extrude(name, 'xz', y, entities, depth, 'cut', target)
        self.m['extrudes'][-1]['profile_indices'] = list(range(len(points)))

    def hex_pocket(self, name, target, y, depth, x, z, af=6):
        r = af / math.sqrt(3)
        self.extrude(name, 'xz', y, self.poly([(x+r*math.cos(i*math.pi/3), z+r*math.sin(i*math.pi/3)) for i in range(6)]), depth, 'cut', target)
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

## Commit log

2026-09-19 Preserve roller design baseline before workspace consolidation
    [BOM.xlsx, carrier-end-section-fit.stl, input-spine-fit.stl]
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2026-09-19 Clear servo adapter supports and check belt tension travel
    [carrier-end-section-fit.stl, input-spine-fit.stl]
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2026-09-20 Replace hidden frame alternatives with single integrated unibody housing
2026-09-20 Replace inherited frame with shell-first barrel and structural hatch
    [BOM.xlsx, curved-hatch-assembly-coordinates.stl, curved-hatch-axle-vertical.stl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]
2026-09-20 Add design/ v0.1 modular JSONC scaffolds for Design Ops
    Empty replay-safe chapter scripts (hardware_refs through drive_stack plus assemble orchestrator), VERSION/gen_meta, and README. Geometry still in native master; JSONC is AI-iterate SoT going forward.
2026-09-20 Fill v0.1 coupon geometry for print-today mechanic fit articles
    Add real blank-doc JSONC steps (VERSION 0.1 unchanged): 608 D22.2×7.2
    trial seat + M4 AF7.3×3.5 nut coupons; wheel-seat saddle coupon; HTD3M
    24/48 pitch envelopes + 210-3M-09 belt torus; carriage rail ±1.5 slot.
    Point design/README print-today at scripts and existing first-prints STLs.
2026-09-20 Export printable coupon meshes from v0.1 Design Ops chapters.
    Replay hardware_refs, barrel_shell, and input_carriage on blank docs; land 3MF+STL under first-prints/coupons/ for trial seats.
    [608-seat-coupon.3mf, 608-seat-coupon.stl, carriage-rail-slot-coupon.3mf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]
2026-09-20 Fill v0.1 structural hatch lap/M4 and panel-arc coupons
    JSONC-first S03 coupons from parameters.hatch / PLAN: developed lap+gap+M4 AF7.3×3.5 trial plate, R76–R80×35° skin arc envelope, named hatch refs. Headless replay OK; export print-today meshes. Full 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
    [hatch-lap-m4-coupon.3mf, hatch-lap-m4-coupon.stl, hatch-panel-arc-coupon.3mf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]
2026-09-21 Fill v0.1 electronics_mounts shelf/standoff and allowance coupons
    S04 print-today coupons from recorded nominals (Pi 65×30, Pixracer 36×36, TOF 20×12, battery UNMEASURED tray, TOPDON envelope); export STL/3MF; retainers/depth/aperture remain HOLD.
    [battery-allowance-tray-coupon.3mf, battery-allowance-tray-coupon.stl, pi-shelf-standoff-coupon.3mf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]
2026-09-21 Expand v0.1 input_carriage toward one-drive printable set
    Promote design_v0_1_input_carriage beyond the rail/slot coupon: left_input_carriage with ±1.5 / 7.4×4.4 slots, two D22.2×7.2 input seats, servo case lips from 40.5×20×40.5 only; M3 recessed input cap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
    [carriage-rail-slot-coupon.3mf, carriage-rail-slot-coupon.stl, input-cap-inner.3mf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]
2026-09-21 Deprecate failed one-drive placeholder meshes
    Remove crude JSONC block exports; restore input_carriage to coupon-only. Print SoT for carriage/caps is shell-first-review from native; repo tracks location, sessions are transitory.
    [carriage-rail-slot-coupon.3mf, carriage-rail-slot-coupon.stl, input-cap-inner.3mf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]
2026-09-21 Add native-port body inventory for JSONC SoT tracking
    Inventory Roller-300.nbcad model.json target bodies (shell/carriage/caps/hatch). Repo tracks port progress; sessions are transitory. Next: left_input_carriage body 97.
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2026-09-21 Rebuild left_input_carriage JSONC from native dump (body 97).
    Replace the rail coupon chapter with Extrude62→86 (skip Mirror2), blank-doc
    replay AABB 39×100×35, and export first-prints/native-port meshes.
    [left-input-carriage.3mf, left-input-carriage.stl]
2026-09-21 Port input caps bodies 100/108 to JSONC from native dump.
    Add design_v0_1_input_caps chapter after carriage; blank-doc AABB matches review STLs; export native-port meshes.
    [input-cap-inner.3mf, input-cap-inner.stl, input-cap-outer.3mf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]
2026-09-21 Port wheel caps bodies 56/65 to JSONC from native dump.
    Add design_v0_1_wheel_caps chapter after input_caps; blank-doc AABB matches review STLs; export native-port meshes.
    [wheel-cap-inner.3mf, wheel-cap-inner.stl, wheel-cap-outer.3mf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]
2026-09-21 Dump hatch body 141 and partial JSONC (shell-32 blocker).
    Native feature dump for MoveCopy5→Extrude88∩→fastener cuts; grow structural_hatch
    chapter with VERIFY. Full blank-doc AABB/export blocked until main_shell 32 is ported.
    Legacy lap/M4 + panel-arc coupons retained as print-today note.
2026-09-21 Port main_shell body 32 to barrel_shell JSONC from native dump.
    Replace saddle-coupon chapter with dump→JSONC via tools/dump_to_jsonc.py
    (fid order; skip hatch-only MoveCopy5/Combine8/Combine16). Blank-doc replay
    AABB ~159.93×210×159.96 pre-Combine16; export first-prints/native-port/main-shell.*.
    [main-shell.3mf, main-shell.stl]
2026-09-21 Port hatch body 141 to structural_hatch JSONC from native dump.
    Replay shell through Combine3 (max_fid 290) then MoveCopy5→Extrude88∩/fastener
    patterns; XY AABB matches review STL, Z VERIFY; export curved-hatch.*.
    [curved-hatch.3mf, curved-hatch.stl]
2026-09-21 Close hatch Z and Combine16 VERIFYs on native-port shell/hatch.
    Diagnose tall hatch Z[123,202.932] as native Extrude88@Z123 (review STL zmin
    154.859 is trimmed ID-R76 chord); apply assemble-order Combine8/16 and re-export
    main-shell.*.
    [main-shell.3mf, main-shell.stl]
2026-09-26 Record the carriage rail slot coupon and point T3 Code at this checkout.
    The print coupon was the remaining local work on main.
    [carriage-rail-slot-coupon.3mf]
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2026-09-27 Record the wheel-to-servo drive and drop the expensive limiter.
    The active model keeps the barrel and the load path: wheel between two bearings, a washer slipper on the 48T, and a servo cradle. The old internal plastic stays suppressed.
2026-09-27 Support the barrel only where the shafts and servo bear.
    Each side gets a mouth boss for the inner wheel bearing, a boss for the outer input bearing, a web down to the belly, and a foot under the servo.
2026-09-27 Carry both input bearings on one spine and tie it to the mouth.
    The servo foot now meets the input supports, and a short bridge joins that spine to the wheel-bearing boss.
2026-09-28 Hide sketches and construction planes so the barrel solids are the view.
    The support geometry stays. The old sketch frames no longer draw on top of it.
2026-09-28 Seat the outer wheel bearing in the wheel itself.
    The barrel stops at the inner bearing. The outboard 608 now has a boss in the tire's outboard sidewall.
2026-09-28 Open the outer wheel-bearing boss so the shaft can pass.
    The seat was a closed pocket across the shaft. The 22.2 mm bore now runs the full depth of the boss.
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2026-09-28 Lock the servo in its cradle and the slipper to the shaft.
    The case can no longer slide out the spline end, the shaft washer is driven by a flat, and the 48T is bolted to the pressure washer. Slip torque is still set on the bench.
2026-10-08 Save S21 chassis fit review and staged print projects
    [BOM.xlsx, Roller-300-REX-first-fit.3mf, Roller-300-carrier-roof-trial.3mf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]
